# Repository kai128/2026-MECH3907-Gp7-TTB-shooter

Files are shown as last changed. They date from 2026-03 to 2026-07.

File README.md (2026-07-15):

# Ball Shooting Machine – MECH3907 Group 7

> A three‑wheel table tennis ball launcher with automated aiming, speed control, and ball feeding.  
> Designed and built for the MECH3907 Mechatronic Design and Prototyping course at HKUST.

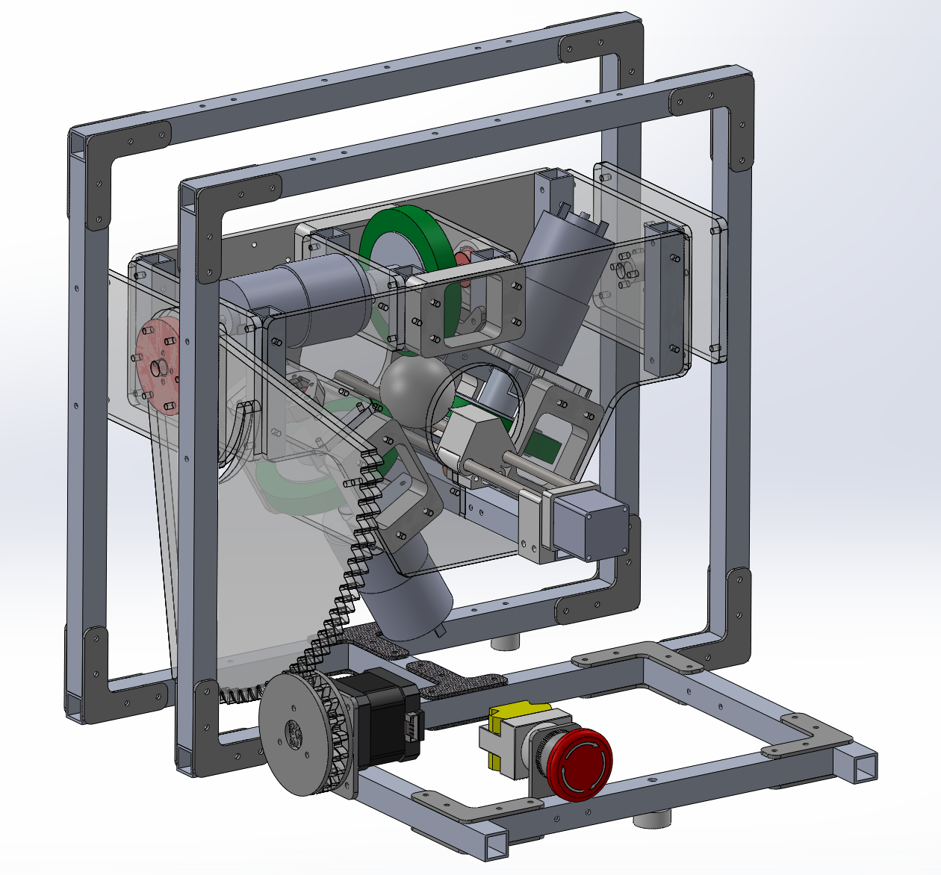
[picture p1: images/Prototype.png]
Prototype
  

---

## Overview

This project is a **fully functional ball launching machine** that demonstrates mechatronic design principles — from mechanical construction to embedded control.  
It features:

- **Three‑wheel flywheel launch mechanism** for stable grip and high ball speed  
- **Pitch control** via stepper motor and sector gear (1:6 torque multiplication)  
- **Closed‑loop speed control** (PID) using AS5600 magnetic encoders  
- **Automatic ball feeder** with a linear stepper motor  
- **Pre‑programmed aiming** for targets at 2 m, 4 m, and 6 m (top/middle/bottom)  
- **Laser pointer** for visual alignment  
- **Safety interlocks** (LED status, loader position check, speed confirmation)

The machine was built on a budget of **~HK$500** and fits within a 400 mm × 400 mm footprint.

---

## Key Specifications

| Parameter | Value |
|---|---|
| **Power supply** | 20 V DC (motors), 5 V (logic) |
| **Power consumption** | ~80 W |
| **Dimensions** | 330 mm × 348 mm × 322 mm |
| **Flywheel motors** | 3× brushed DC (Model 799) |
| **Pitch actuator** | Stepper motor + 120‑tooth sector gear |
| **Ball feeder** | 28‑step linear stepper + leadscrew |
| **Encoders** | 3× AS5600 (magnetic, I²C) |
| **Multiplexer** | TCA9548A (for multiple I²C devices)|
| **Motor drivers** | A4988 / DRV8825 (steppers), H‑bridge (DC) |
| **Microcontroller** | Arduino UNO |
| **Material** | Aluminium frame, acrylic housing, 3D‑printed parts |

---

## How It Works

1. **Setup** – The shooter is placed on the table. Pitch angle and flywheel speeds are selected via pre‑stored parameters in the Arduino code.
2. **Safety check** – The system verifies that the ball loader is retracted and that all three wheels have reached the target RPM (green LED = ready).
3. **Launch** – The feeder pushes the ball into the three‑wheel gap. The spinning PU wheels grip, compress, and accelerate the ball out.
4. **Closed‑loop control** – AS5600 encoders continuously report speed; PID adjusts PWM to maintain stable velocity.
5. **Automated targeting** – For competition, the machine alternates between middle and bottom targets at each distance without manual intervention.

---

## Mechanical Design Highlights

### Three‑Wheel Launching System
- Wheels arranged 120° apart for **symmetric grip** and minimal vertical drift.
- Polyurethane wheels deform to increase contact area and friction, maximising energy transfer.
- Upper wheel is fixed (after iterative removal of a tension spring) to ensure simultaneous contact with the lower pair.

### Frame & Housing
- **Aluminium base** – rigid and heavy to damp vibration and recoil.
- **Acrylic housing** – laser‑cut for fast prototyping; holds motors securely.

### Pitch Adjustment
- Stepper motor drives a 20‑tooth pinion engaging a 120‑tooth sector gear (ratio 1:6).
- High holding torque keeps the launcher stable at the desired angle.
- *Pitch motor behaved unstable. Please consider increasing the gear ratio.*

### Automatic Ball Feeder
- A linear stepper with leadscrew moves a 3D‑printed carriage smoothly forward to feed the ball.
- Returns to home position after each shot.

---

## Hardware & Software

### Electronics Layout
- **Main controller:** Arduino UNO
- **Power distribution:** 20 V → emergency stop → fused branches for each motor; 5 V for logic via DC‑DC converter.
- **I²C bus:** TCA9548A multiplexer to separate three AS5600 encoders (fixed address 0x36).
- **Motor drives:** Separate H‑bridge per flywheel motor for independent speed tuning.

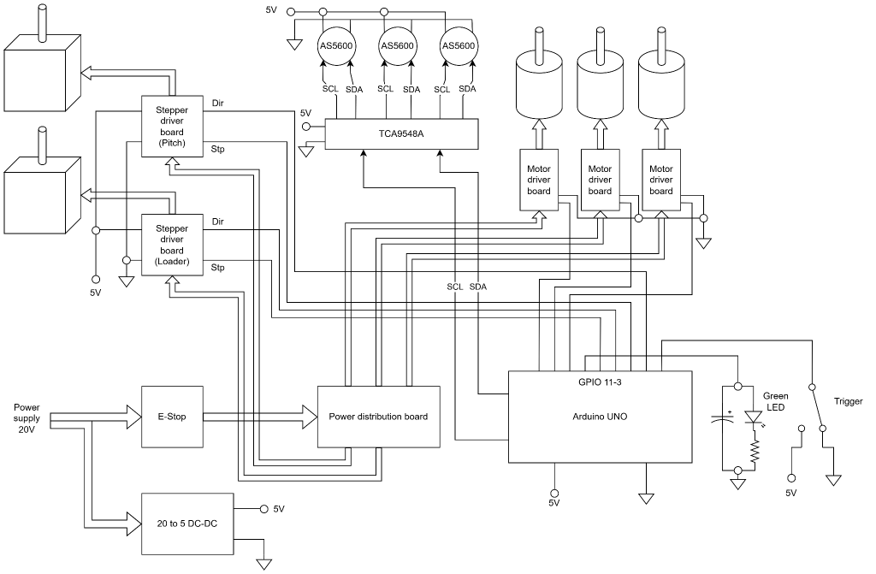
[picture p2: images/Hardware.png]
Hardware Flowchart
  
### Software Features
- **PID control** on each flywheel for consistent RPM.
- **Low‑pass filtering** on encoder readings to reduce noise.
- **Safety workflow:** Green LED indicates ready; trigger disabled if loader not home or speeds not reached.
- **Pre‑programmed parameter sets** for different distances and target heights (angle, speed).

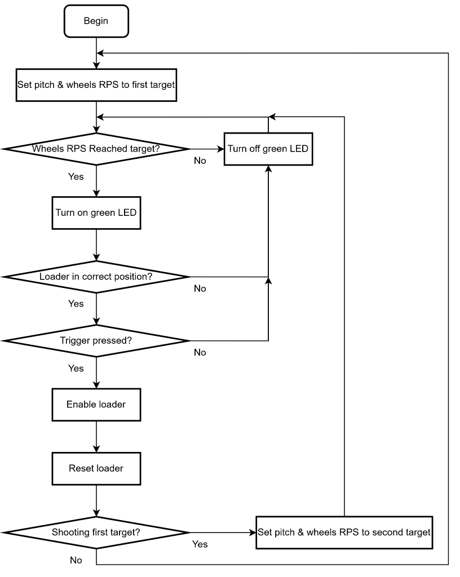
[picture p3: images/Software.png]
Software Flowchart
  

---

## Bill of Materials (BOM)

The final build cost was **~HK$500.76**.

*Full BOM with part numbers is available in ./Budget.xlsx.*

---

## Competition Results

In the final demonstration, we achieved:

| Distance | Score (best attempt) |
|---|---|
| 2 m | 10 points (Bottom) |
| 4 m | 2 points (Bottom) |
| 6 m | – |

*Although the 6 m target proved challenging, the machine demonstrated consistent behaviour and reliable automation.*

---

## License

This project is **open‑source** and released under the **[Creative Commons Attribution‑NonCommercial 4.0 International License](https://creativecommons.org/licenses/by-nc/4.0/)**.

- You are free to **use, modify, and share** this project for **non‑commercial** purposes.
- ommercial use is **not permitted** without explicit permission.
- Please give appropriate credit to the original authors.

---

## Acknowledgements

- Inspired by the **AIMY** open‑source table tennis launcher (Max Planck Institute for Intelligent Systems) and the HKUST Robotics Team 2025 FDR1.
- Course instructors and lab technicians for guidance and facilities.
- Names of group members are removed from the reports to protect privacy.

---

## Contact

For questions or collaboration (non‑commercial), please open an issue or reach out via the repository.

---

**Enjoy building and shooting!**

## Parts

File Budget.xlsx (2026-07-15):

Item no. | Item |  | Qty | Payment Currency | Unit Price | Amount (Currency)
 |  |  |  |  |  | CNY
1 | PU wheels | https://item.taobao.com/item.htm?from=cart&id=977597886476&skuId=5933876197883&upStreamPrice=3300 | 3 | CNY | 33 | CNY 99.00
2 | 42 Stepper | https://item.taobao.com/item.htm?id=911339126038&last_time=1770621623&upStreamPrice=1500&skuId=5942512971982 | 1 | CNY | 19 | CNY 19.00
3 | Encoder | https://item.taobao.com/item.htm?id=610353164151&last_time=1770618794&upStreamPrice=473&skuId=4532825905535 | 3 | CNY | 5 | CNY 15.00
4 | 28 Stepper w. Lead screw w. nut | https://detail.tmall.com/item.htm?from=cart&id=939200941082&skuId=6001434703301&upStreamPrice=2200 | 1 | CNY | 22 | CNY 22.00
5 | Shaft | https://detail.tmall.com/item.htm?id=723936088400&last_time=1770621912&skuId=5029064740093&upStreamPrice=550 | 1 | CNY | 5.5 | CNY 5.50
6 | Linear bearing |  | 2 | CNY | 3 | CNY 6.00
7 | Coupler | https://item.taobao.com/item.htm?from=cart&id=567933755449&skuId=4104578295409&upStreamPrice=2400 | 3 | CNY | 25 | CNY 75.00
8 | Z21 - 5*16*11 | https://item.taobao.com/item.htm?id=588096657853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 | 1 | CNY | 15.8 | CNY 15.80
9 | XRU1008UUCC0/P5 | https://item.taobao.com/item.htm?id=773044688198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 | 1 | CNY | 68 | CNY 68.00
10 | F626ZZ | https://item.taobao.com/item.htm?id=787710083854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 | 3 | CNY | 2.75 | CNY 8.25
11 | shoulder screw |  | 1 | CNY | 11.18 | CNY 11.18
12 | Custom GFP/acrylic/3DP/AlTubes |  | 1 | CNY | 0 | CNY 0.00
13 | DC motor driver board |  | 3 | CNY | 13.2 | CNY 39.60
14 | Stepper driver board | https://item.taobao.com/item.htm?from=cart&id=584769820744&skuId=5201224983975&upStreamPrice=670 | 2 | CNY | 6.7 | CNY 13.40
15 | Arduino (mainland ver.) | https://detail.tmall.com/item.htm?id=668740881607&last_time=1770623640&skuId=4965377312682&upStreamPrice=1039 | 1 | CNY | 25.65 | CNY 25.65
16 | TCA9548A | https://item.taobao.com/item.htm?from=cart&id=837011425535&skuId=5762086830849&upStreamPrice=1056 | 1 | CNY | 10.56 | CNY 10.56
17 | Trigger button | https://item.taobao.com/item.htm?from=cart&id=837011425535&skuId=5762086830849&upStreamPrice=1056 | 1 | CNY | 1.5 | CNY 1.50
 |  |  |  | Grand Total |  | ¥435.44
 |  |  |  |  |  | HK$500.76
50.00

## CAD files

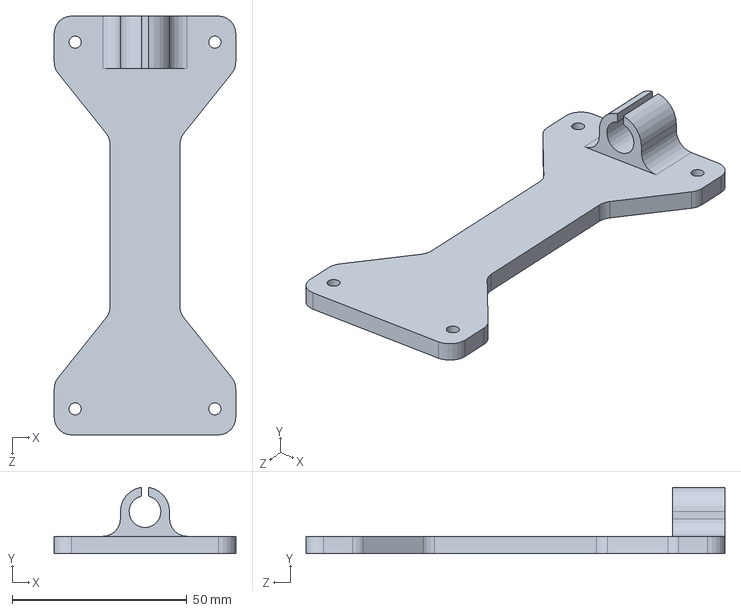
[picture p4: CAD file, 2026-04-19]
slw/3DP/3907BS_3DP12.SLDPRT
52.0 x 19.0 x 120.0 mm

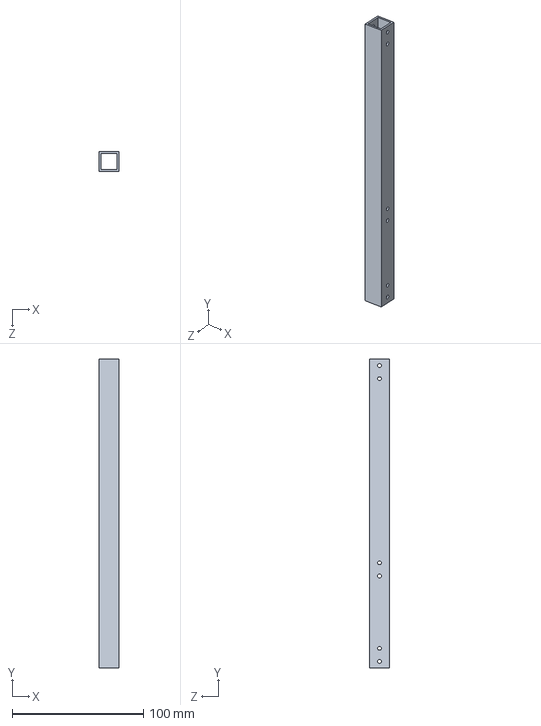
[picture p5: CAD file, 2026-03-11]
slw/AlTube/3907BS_AlTube02.SLDPRT
15.0 x 235.0 x 15.0 mm

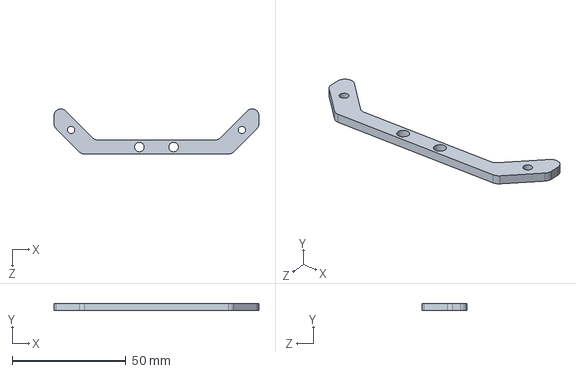
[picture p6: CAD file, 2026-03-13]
slw/GFP/3907BS_3GFP01.SLDPRT
90.0 x 3.00 x 19.9 mm

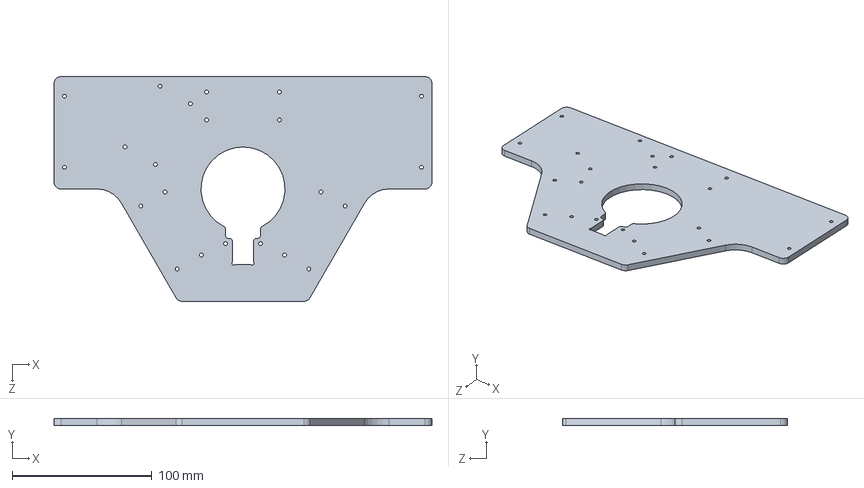
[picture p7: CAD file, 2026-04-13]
slw/LSC/3907BS_LSC05.SLDPRT
270.0 x 5.00 x 160.6 mm

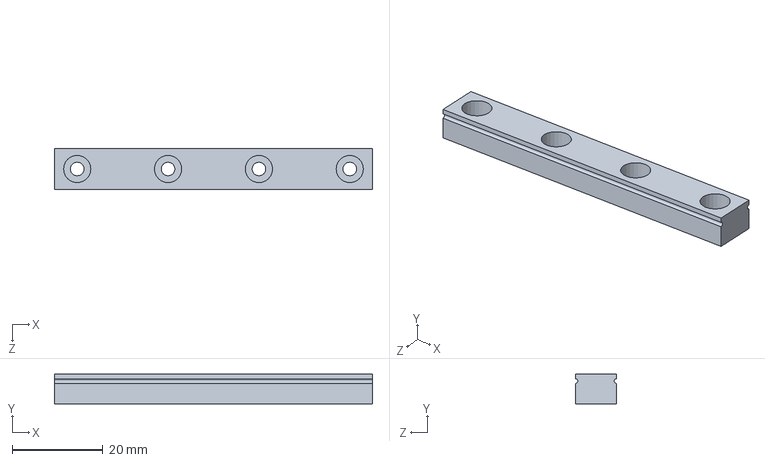
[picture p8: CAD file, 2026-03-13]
slw/Misc/9mm LM Guide.SLDPRT
70.0 x 6.50 x 9.00 mm

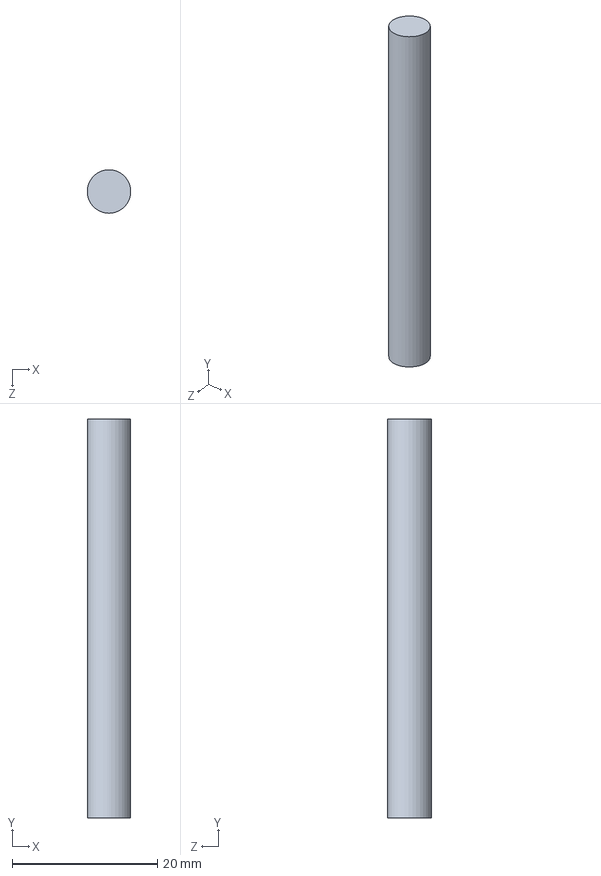
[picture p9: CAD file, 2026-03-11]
slw/Shaft/3907BS_6Shaft02.SLDPRT
5.99 x 55.0 x 6.00 mm

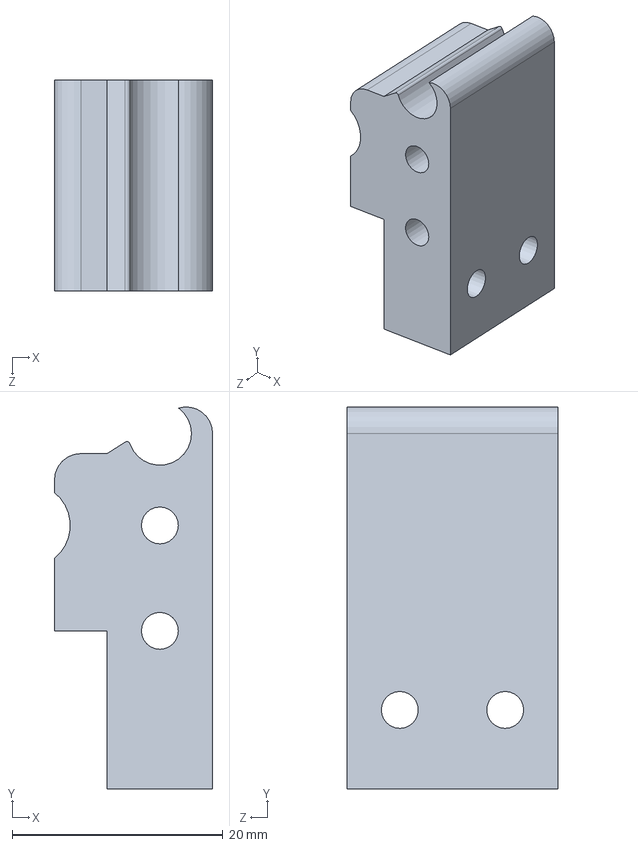
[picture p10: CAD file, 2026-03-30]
slw/3DP/3907BS_3DP05.SLDPRT
15.0 x 36.2 x 20.0 mm

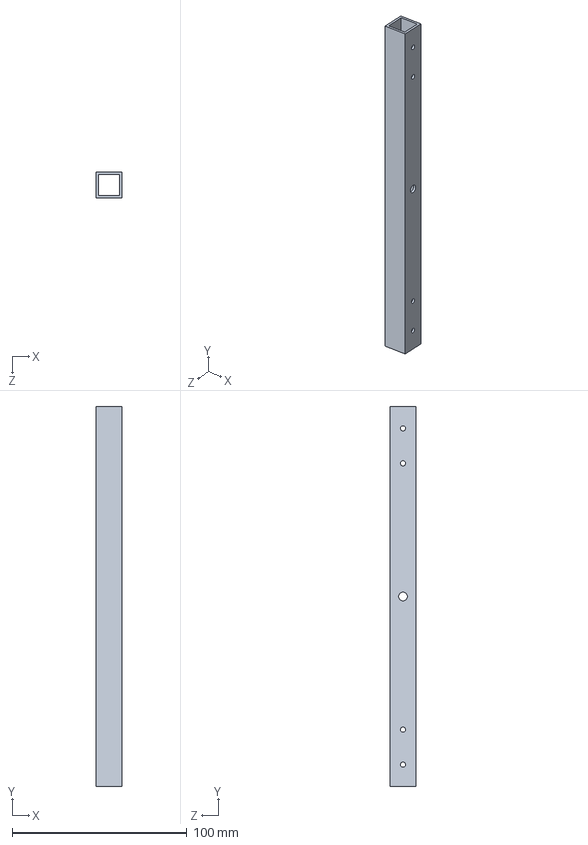
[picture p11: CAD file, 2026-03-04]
slw/AlTube/3907BS_AlTube08.SLDPRT
15.0 x 217.3 x 15.0 mm

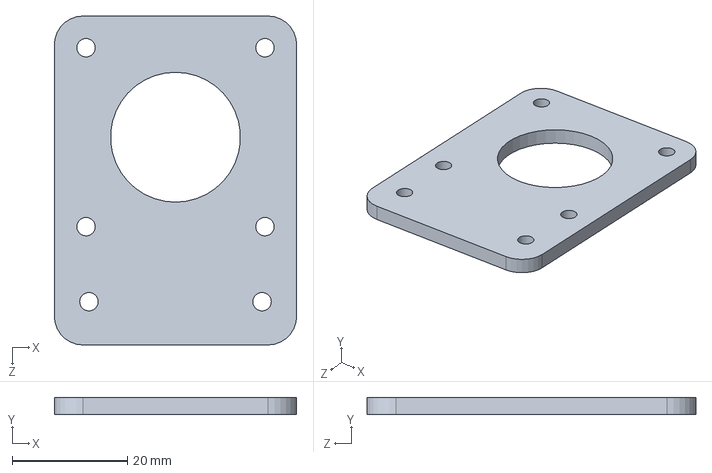
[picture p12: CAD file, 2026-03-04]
slw/GFP/3907BS_3GFP03.SLDPRT
42.0 x 3.00 x 57.0 mm

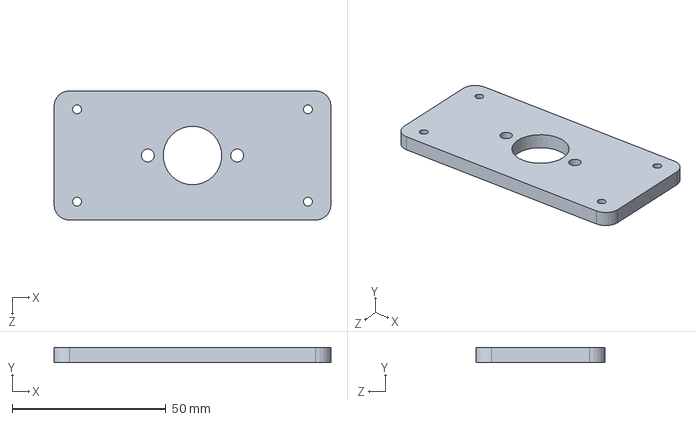
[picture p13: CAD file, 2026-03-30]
slw/LSC/3907BS_LSC06.SLDPRT
90.0 x 5.00 x 42.0 mm

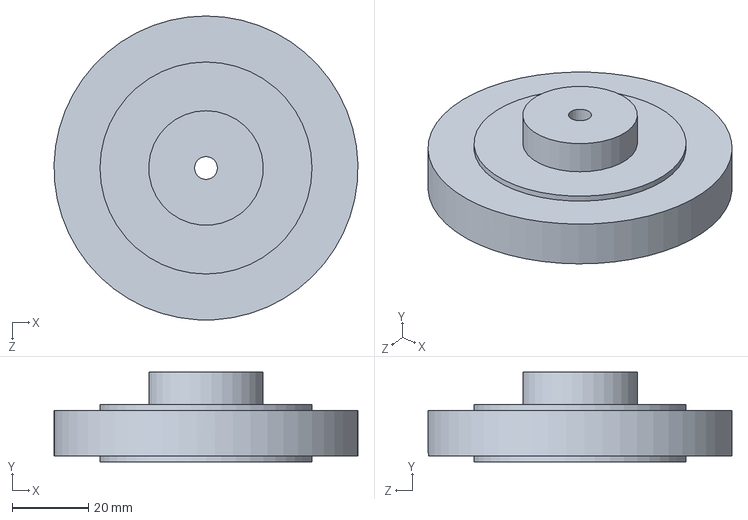
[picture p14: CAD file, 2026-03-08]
slw/Misc/LZNJ-250.SLDPRT
79.5 x 23.5 x 79.6 mm

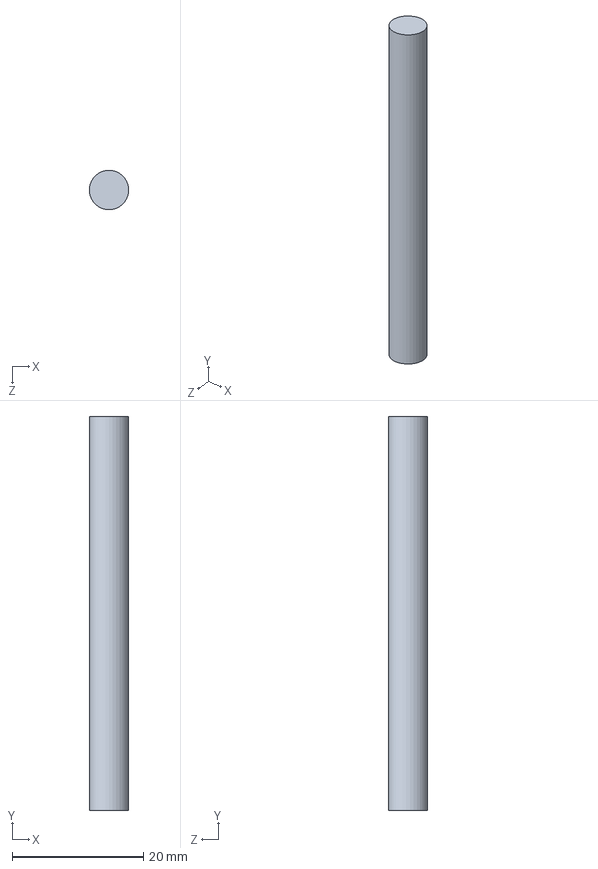
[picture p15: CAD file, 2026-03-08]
slw/Shaft/3907BS_6Shaft01.SLDPRT
5.97 x 60.0 x 6.00 mm

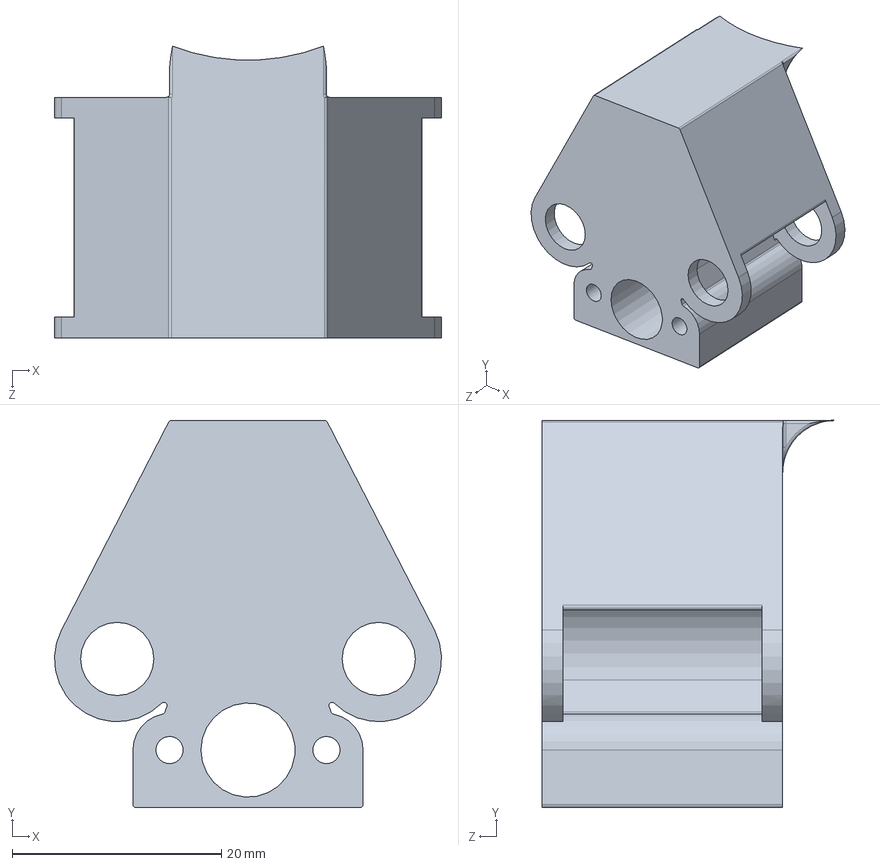
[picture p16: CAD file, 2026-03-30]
slw/3DP/3907BS_3DP06.SLDPRT
37.0 x 37.0 x 27.9 mm

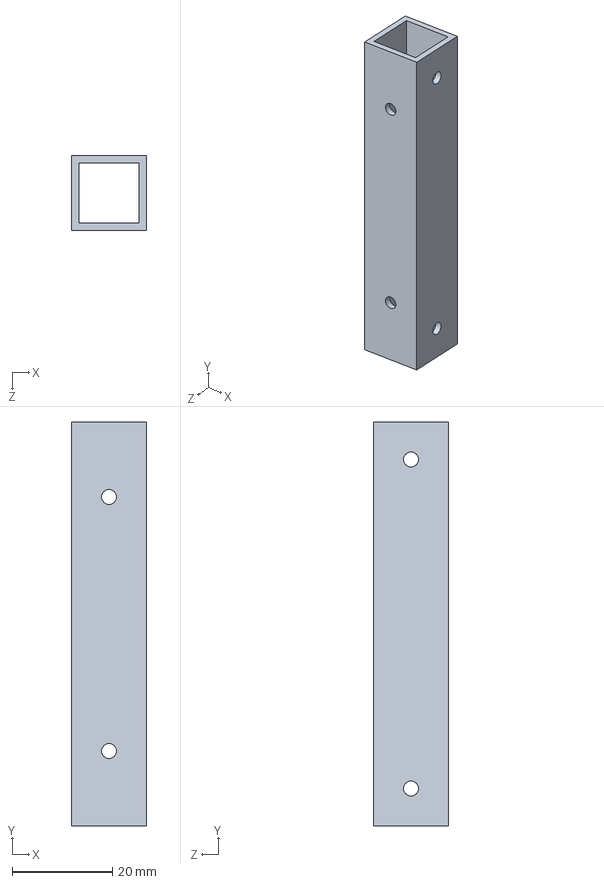
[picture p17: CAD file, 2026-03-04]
slw/AlTube/3907BS_AlTube03.SLDPRT
15.0 x 80.8 x 15.0 mm

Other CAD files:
slw/3907BS.SLDASM
slw/3907BS_FW.SLDASM
slw/3907BS_IR.SLDASM
slw/GFP/3907BS_3GFP05.SLDPRT
slw/3DP/3907BS_3DP01.SLDPRT
slw/3DP/3907BS_3DP02.SLDPRT
slw/3DP/3907BS_3DP03.SLDPRT
slw/3DP/3907BS_3DP04.SLDPRT
slw/3DP/3907BS_3DP07.SLDPRT
slw/3DP/3907BS_3DP08.SLDPRT
slw/3DP/3907BS_3DP09.SLDPRT
slw/3DP/3907BS_3DP10.SLDPRT
slw/3DP/3907BS_3DP11.SLDPRT
slw/AlTube/3907BS_AlTube01.SLDPRT
slw/AlTube/3907BS_AlTube04.SLDPRT
slw/AlTube/3907BS_AlTube05.SLDPRT
slw/AlTube/3907BS_AlTube06.SLDPRT
slw/AlTube/3907BS_AlTube07.SLDPRT
slw/GFP/3907BS_3GFP02.SLDPRT
slw/GFP/3907BS_3GFP04.SLDPRT
slw/GFP/Template90LShape(15mm).SLDPRT
slw/GFP/Template90TShape(15mm).SLDPRT
slw/LSC/3907BS_LSC01.SLDPRT
slw/LSC/3907BS_LSC02.SLDPRT
slw/LSC/3907BS_LSC03.SLDPRT
slw/LSC/3907BS_LSC04.SLDPRT
slw/LSC/3907BS_LSC07.SLDPRT
slw/LSC/3907BS_LSC08.SLDPRT
slw/LSC/3907BS_LSC09.SLDPRT
slw/Misc/28stepper w leadScrews.SLDPRT
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

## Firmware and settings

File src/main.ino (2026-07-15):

#define IRSensorDistance 200 // Distance between two IR in mm
#define LoaderMovingDistance 73 // Distance for the loader to move when loading in mm
#define NumberOfMotor 3
#include <stdlib.h>
#include <Wire.h>

// Define the usage for Pins
#define TriggerPin 3
#define PitchDirPin 4
#define PitchStpPin 5
#define LoadDirPin 6
#define LoadStpPin 7
#define GreenLEDPin 8
#define TopMotorPin 9
#define BLMotorPin 10
#define BRMotorPin 11
#define IR1Pin 12
#define IR2Pin 13


#define TCA9548A_ADDR  0x70   // Default I2C address of TCA9548A
#define AS5600_ADDR     0x36  // Fixed I2C address of AS5600

#define ANGLE_HIGH_REG  0x0C  // AS5600 angle register (high byte 0x0C, low byte 0x0D)

#define SAMPLE_INTERVAL 10 // Sampling interval in milliseconds

// ======================== PID Parameters ========================
float Kp = 2.8;
float Ki = 0.17;
float Kd = -0.05;
// ================================================================

float targetRPS[3] = {0, 0, 0};
float dt[3];

struct Target {
  float speed;
  int angle;
};
Target shootingTarget[2];


struct Encoder {
  float lastAngle;       // Previous raw angle (0..4095)
  unsigned long lastTime;       // Previous timestamp (ms)
  float rps;                    // Last computed RPS
  float avg={0};
};
Encoder encoderData[3];



struct PID {
  float integral;
  float prevError;
};
PID pidData[3];

float getEncoderData();
void selectTCAChannel(uint8_t channel);
uint16_t readAS5600Angle();

float computePID(uint8_t motorIndex, float setpoint, float measurement, float dt);
void setMotorSpeed(uint8_t motorIndex, float pwmValue);
void configPins(float dt);
void setPitchAngle(uint16_t targetAngle);
void calculateSpeed(float TargetBallSpeed);

int pitchAngle = 488; // The angle times 10



void setup() {
  delay(2000);
  Serial.begin(115200);
  while (!Serial);
  configPins();
  Wire.begin();
  digitalWrite(GreenLEDPin, 0);
  for (int ch = 0; ch < NumberOfMotor; ch++) {
    selectTCAChannel(ch);
    delay(10);
    Serial.println(ch);
    encoderData[ch].lastAngle = readAS5600Angle();
    
    encoderData[ch].lastTime = millis();
    encoderData[ch].rps = 0.0;

    pidData[ch].integral = 0.0;
    pidData[ch].prevError = 0.0;
  }
  // 2 meter: Top: 450, 10.55; Middle: 190, 10; Bottom: 100, 6.35
  // 4 meter: Top: ; Middle: 200, 14.3; Bottom: 100, 12.83;
  // 6 meter: Top: 300, 18; Middle: 230/225, 17.5; Bottom: 150, 17.5
  // Setup first target para
  shootingTarget[0].angle = 190;
  shootingTarget[0].speed = 10;
  // Setup second target para
  shootingTarget[1].angle = 100;
  shootingTarget[1].speed = 6.35;
  // Setup motor rps using Target ball speed and rps;
  calculateSpeed(shootingTarget[0].speed);
  setPitchAngle(shootingTarget[0].angle);
}

void loop() {
  uint8_t datainput = 0;
  static bool loaderEnable = false;
  static bool loaderUp = false;
  static uint16_t loaderPos = 0;
  static bool targetNum = 0;

  // Check if shooter is ready
  bool shooterReady = true;
  for (uint8_t i = 0; i < NumberOfMotor; i++) {
    if (encoderData[i].rps < targetRPS[i] * 0.90 || encoderData[i].rps > targetRPS[i] * 1.1 ) {
      shooterReady = false;
    }
    
  }
  shooterReady &= !loaderUp;
  shooterReady &= !loaderEnable;
  digitalWrite(GreenLEDPin, shooterReady);
  // Loader - load TTB when trigger was pressed then return
  if (digitalRead(TriggerPin) && shooterReady) {
    loaderEnable = true;
  }
  if (loaderEnable) {
    if (!loaderUp) {
      digitalWrite(LoadDirPin, 1);
      digitalWrite(LoadStpPin, HIGH);
      delay(1);
      digitalWrite(LoadStpPin, LOW);

      loaderPos++;
      //Serial.println(loaderPos);
    }
    else {
      digitalWrite(LoadDirPin, 0);
      digitalWrite(LoadStpPin, HIGH);
      delay(1);          
      digitalWrite(LoadStpPin, LOW);

      loaderPos--;
    }
    
    if (loaderPos >= 50 * LoaderMovingDistance || loaderPos <= 0) {
      loaderUp = !loaderUp;
      if (!loaderUp) {
        loaderEnable = false;
        targetNum = !targetNum;
        calculateSpeed(shootingTarget[targetNum].speed);
        setPitchAngle(shootingTarget[targetNum].angle);
        
      }
    }
  }

    
  getEncoderData();
  setMotorSpeed();
}

float getEncoderData() {
  static unsigned long lastPrint = 0;
  static unsigned long lastPrint2 = 0;
  unsigned long now = millis();
  if (now - lastPrint2 >= 90) {

    lastPrint2 = now;
    char RPSString[] = "> avg1:";
    for (int i = 0; i < NumberOfMotor; i++) {
      RPSString[5] = i + '1';
      Serial.print(RPSString);
      Serial.print(encoderData[i].avg, 2);
      RPSString[0] = ',';
    }
    Serial.println();
    
  }
  if (now - lastPrint >= SAMPLE_INTERVAL) {
    lastPrint = now;
    for (int ch = 0; ch < NumberOfMotor; ch++) {
      // Select the desired channel on the TCA9548A
      selectTCAChannel(ch);
      //delay(2);                  // Short delay to let the mux settle

      // Read the angle from the AS5600 on the currently active channel
      
      
      //Serial.println(ch);
      uint16_t rawAngle = readAS5600Angle();
      

      // Calculate time difference (seconds)
      unsigned long dt_ms = now - encoderData[ch].lastTime;
      float dt_s = dt_ms / 1000.0;

      // Convert raw 12‑bit value to degrees (0.0 – 360.0)
      float rev = rawAngle / 4096.0;
      
      // Handle wrap-around
      if (encoderData[ch].lastAngle - rev > 0.001) {
        encoderData[ch].lastAngle -= 1;
      }
      float delta_rev = rev - encoderData[ch].lastAngle;

      // Compute RPS
      // Tons of magic numbers of signal filtering 
      float accel = (delta_rev / dt_s - encoderData[ch].rps) / dt_s;
      if (dt_s > (SAMPLE_INTERVAL + 0.1) / 2000.0 && delta_rev / dt_s < 110 && delta_rev > 0.07 && abs(accel) < 8000)  {
        encoderData[ch].rps = delta_rev / dt_s;
      }else {encoderData[ch].rps -= (encoderData[ch].rps > 0)? 1 : 0;}

      // Low-pass filter
      encoderData[ch].avg = (encoderData[ch].rps > 0)? (1-0.1) * encoderData[ch].avg + (0.1) * encoderData[ch].rps : 0;

      // Store current values for next iteration
      encoderData[ch].lastAngle = rev;
      encoderData[ch].lastTime = now;
      dt[ch] = dt_s;
    }
  }
}


/*
 * Select a channel on the TCA9548A.
 * channel: 0..7 for the eight possible channels.
 */
void selectTCAChannel(int channel) {
  int channelIndex[] = {0, 4, 2};
  if (channel > 7) return;                     // Safety check
  Wire.beginTransmission(TCA9548A_ADDR);
  Wire.write(0x01 << channelIndex[channel]);  // Send channel select byte
  //Serial.println(0x01 << channel);                   
  Wire.endTransmission();
}

/*
 * Read the 12‑bit angle from the AS5600.
 * Returns a value between 0 and 4095.
 */
uint16_t readAS5600Angle() {
  Wire.beginTransmission(AS5600_ADDR);
  Wire.write(ANGLE_HIGH_REG);                   // Point to the high byte of the angle
  if (Wire.endTransmission(false) != 0) {       // Send repeated start
    Serial.println("Error communicating with AS5600");
    return 0;
  }

  // Request 2 bytes from the AS5600
  Wire.requestFrom(AS5600_ADDR, 2);
  if (Wire.available() >= 2) {
    uint8_t highByte = Wire.read();              // High byte (bits 11..8)
    uint8_t lowByte  = Wire.read();              // Low byte  (bits 7..0)
    return ( (highByte << 8) | lowByte ) & 0x0FFF; // Mask to 12 bits
  } else {
    Serial.println("Failed to read enough bytes from AS5600");
    return 0;
  }
}

float computePID(uint8_t motorIndex, float setpoint, float measurement, float dt) {
  float error = setpoint - measurement;

  // Proportional term
  float P = Kp * error;

  // Integral term (with anti-windup: clamp integral)
  pidData[motorIndex].integral += error * dt;
  // Simple integral clamping – adjust limits as needed
  float maxIntegral = 255.0 / (Ki + 0.001);   // Rough limit based on max PWM
  if (pidData[motorIndex].integral > maxIntegral) pidData[motorIndex].integral = maxIntegral;
  if (pidData[motorIndex].integral < -maxIntegral) pidData[motorIndex].integral = -maxIntegral;
  float I = Ki * pidData[motorIndex].integral;

  // Derivative term (on measurement to avoid derivative kick)
  float D = Kd * ( (measurement - (setpoint - error)) / dt );  // Actually we need previous measurement

  D = Kd * (error - pidData[motorIndex].prevError) / dt;
  pidData[motorIndex].prevError = error;

  // Total output
  float output = P + I + D;

  // Constrain output to PWM range (0-255)
  // output < 15 for dead zone
  if (output < 15) output = 0;
  if (output > 255) output = 255;

  return output;
}


void calculateSpeed(float TargetBallSpeed) {
  float TargetBallRPS = 40;
  float TopRPS = (TargetBallSpeed * 2 / 0.25 + TargetBallRPS * (0.04 * 3.14) / 0.25) / 2;
  float BottomRPS = (TargetBallSpeed * 2 / 0.25 - TargetBallRPS * (0.04 * 3.14) / 0.25) / 2;
  targetRPS[0] = TopRPS;
  targetRPS[1] = BottomRPS;
  targetRPS[2] = BottomRPS;
  for (uint8_t i = 0; i < 3; i++) {
    Serial.print("targetRPS");
    Serial.print(i);
    Serial.print(": ");
    Serial.println(targetRPS[i]);
  }
}


void setMotorSpeed() {
  for (uint8_t ch = 0; ch < NumberOfMotor; ch++) {
    float pwmValue = computePID(ch, targetRPS[ch], encoderData[ch].avg, dt[ch]);
    //Serial.println(pwmValue);
    analogWrite(ch + TopMotorPin, (int) pwmValue);
    //analogWrite(ch + TopMotorPin, (int) 255);
  }
}

void setPitchAngle(int targetAngle) {
  bool pitchDir = (targetAngle > pitchAngle)? 0 : 1;
  Serial.print("Delta angle: ");
  Serial.println((targetAngle-pitchAngle));
  digitalWrite(PitchDirPin, pitchDir);
  for (int i = 0; i < (int) abs((targetAngle-pitchAngle)) * 120 / 20 / 18; i++) {
    digitalWrite(PitchStpPin, HIGH);
    delay(8);
    digitalWrite(PitchStpPin, LOW);
    delay(2);
  }
  pitchAngle = targetAngle;
}



void configPins() {
  pinMode(TriggerPin, INPUT);

  pinMode(PitchDirPin, OUTPUT);
  pinMode(PitchStpPin, OUTPUT);

  pinMode(LoadDirPin, OUTPUT);
  pinMode(LoadStpPin, OUTPUT);

  pinMode(GreenLEDPin, OUTPUT);

  pinMode(TopMotorPin, OUTPUT);
  pinMode(BLMotorPin, OUTPUT);
  pinMode(BRMotorPin, OUTPUT);

  pinMode(IR1Pin, INPUT);
  pinMode(IR2Pin, INPUT);
}

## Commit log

2026-02-26 First commit
    Upload SLW CAD and some code.
    [28stepper w leadScrews.SLDPRT, 3907BS.SLDASM, 3907BS_3DP01.SLDPRT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]
2026-02-26 Update init and encoder
    Init of pins, read encoders pos and velocity.
2026-02-27 Add PID
    Applied PID control to motors based on encoder readings.
2026-02-27 Plotting Motor RPS
2026-02-27 Loader & IR
    Code for sensing TTB init velocity and loader steeper control.
2026-03-02 Loader debug
    Avoided the loader crashing after loading.
    [main.ino]
2026-03-02 Loader debug
    static unit16_t i; in wrong place
    [main.ino]
2026-03-02 Update Budget.xlsx
    Update bought items.
    [Budget.xlsx]
2026-03-04 Update slw
    Change GFP to LSC, fix mech bugs, add IR sensors, nested LSC DXF.
    [3907BS.SLDASM, 3907BS_3DP02.SLDPRT, 3907BS_3DP03.SLDPRT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]
2026-03-07 Apply low-pass filter
    Applied low-pass filter to encoder readings.
    [3907BS.SLDASM, 3907BS_3DP01.SLDPRT, 3907BS_3DP01.STEP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]
2026-03-08 Apply PWM control.
    Update flywheel SLW, adjusted PID value.
    [3907BS.SLDASM, 3907BS_3DP03.SLDPRT, 3907BS_6Shaft01.SLDPRT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]
2026-03-09 Motor PRS calculate
    Applied code for calculating motor RPS using Ball speed and RPS.
2026-03-11 Update tubes drawings
    Al Tubes drawings and 3dp step added
    [3907BS.SLDASM, 3907BS_3DP01.STEP, 3907BS_3DP02.STEP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]
2026-03-11 Update BOM
    Screw added in BOM
    [3907BS.SLDASM, 3907BS_BOM.xlsx]
2026-03-13 Encoder code fix
    better encoder reading
    [3907BS.SLDASM, 3907BS_3GFP01.DXF, 3907BS_3GFP01.SLDPRT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]
2026-03-16 Bug fixed for connecting to all encoder
    Fixed an error when selecting TCA channel.
    [main.ino]
2026-03-16 PWM control for 3 motors
    Finished code for controlling all three motors using PID.
2026-03-16 Motor control and loader
    Now the motor PID control will not be blocked by the loader control.
2026-03-30 Update SLW
    Adjusted SOLIDWORKS CAD to lower the loading shafts.
    [3907BS.SLDASM, 3907BS_3DP05.SLDPRT, 3907BS_3DP05.step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]
2026-04-13 Update SLW
    LSC05 updated
    [3907BS.SLDASM, 3907BS_FW.SLDASM, 3907BS_LSC05.DXF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]
2026-04-13 Pitch code
    Added code for pitch
    [3907BS.SLDASM]
2026-04-19 Pitch
    Fixed code for pitching
    [3907BS.SLDASM, 3907BS_3DP12.SLDPRT, 3907BS_3DP13.STEP]
2026-07-15 After D day (#1)
    * D-Day code
    Safety check, green LED, trigger
    * Shooting data
    Added some data in comment
    * I2C and LED
    I2C no longer need to be between 0-2;
    LED less blinking
    * Delay
    Added delay at the start
    [3907BS.SLDASM, Budget.xlsx]
2026-07-15 Readme
    Finished writing README.md
    [3907BS.SLDASM, 3907BS_3DP01.STEP, 3907BS_3DP02.STEP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]
